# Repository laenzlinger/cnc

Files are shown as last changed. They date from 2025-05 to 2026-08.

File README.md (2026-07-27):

# SRCNC

This repository contains the code for my SRCNC project.
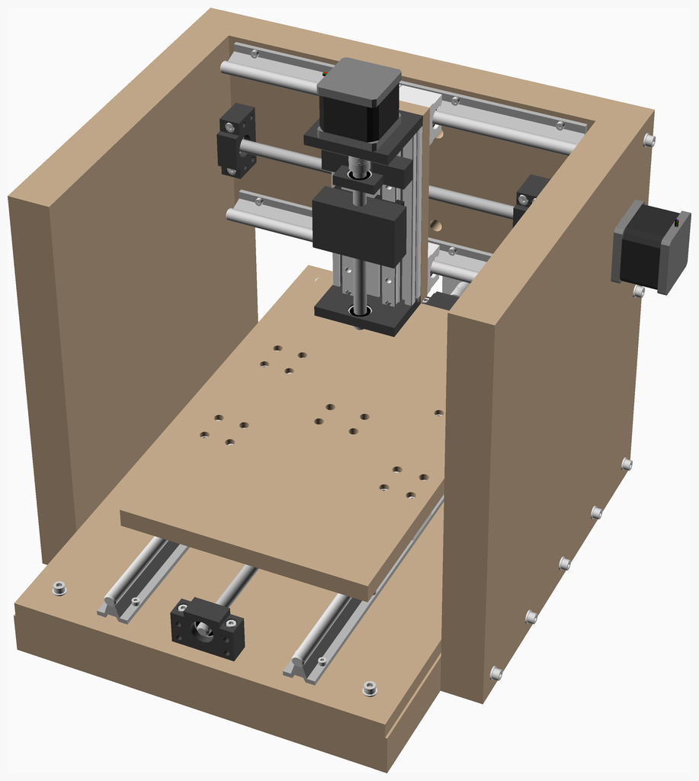
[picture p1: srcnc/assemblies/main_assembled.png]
Main Assembly


It contains configurations for my machine and several parts that I have designed for my CNC machine.

## Assembly

See [instructions](srcnc/readme.md)

## BOM

The below table just lists the main components. For a complete BOM see the assembly instructions above.

| Amount | Description | Source |
|--:|:---|:---|
|  2 | SBR12UU, rail 550mm | [AliExpress](https://www.aliexpress.com/item/1005008976304126.html) |
|  2 | SBR12UU, rail 350mm | [AliExpress](https://www.aliexpress.com/item/1005008976304126.html) |
|  1 | SFU1204 Set, 550mm | [AliExpress](https://www.aliexpress.com/item/1005004058956836.html) |
|  1 | SFU1204 Set, 350mm | [AliExpress](https://www.aliexpress.com/item/1005004058956836.html) |
|  1 | Openbuilds Nema 23 Stepper Motor Mount | [AliExpress](https://www.aliexpress.com/item/1005008656695586.html) |
|  3 | Nema 23 Stepper Motor | [AliExpress](https://www.aliexpress.com/item/1005006435245504.html) |
|  5 | CR10 Endstop | [AliExpress](https://www.aliexpress.com/item/1005001599112235.html) |
| 16 | M6 Threaded insert nut | [AliExpress](https://www.aliexpress.com/item/1005008275463912.html) |
|  1 | Openbuilds Router Spindle Mount 65mm | [AliExpress](https://www.aliexpress.com/item/1005007218914903.html) |
|  1 | Double Square Linear Guide Sliding Table 100mm | [AliExpress](https://www.aliexpress.com/item/1005005320373835.html) |

## Electronics

Built following [PrintNC electronics guidelines](https://wiki.printnc.info/en/electronics) for future migration to a PrintNC build.

| Amount | Description | Source |
|--:|:---|:---|
|  1 | MKS DLC32 MAX V1.1 (ESP32-S3) | [AliExpress](https://www.aliexpress.com/item/1005005320373835.html) |
|  3 | DM542T Stepper Driver | |
|  1 | HLTNC 3D Touch Probe | |
|  1 | Auto-zero Z Touch Plate | |

Spindle: Manual router (no VFD)

Firmware: [FluidNC v4.0.3](https://github.com/bdring/FluidNC)

See [wiring documentation](fluidnc/SRcnc-dlc32max/README.md)

## Libs

<https://github.com/nophead/NopSCADlib>

## Repository Structure

```
cnc/
  fluidnc/          — FluidNC firmware configs (MKS DLC32 MAX, TinyBee)
  grblhal/          — grblHAL configs (Flexi-HAL, future)
  ugs/              — Universal G-code Sender config and macros
  probe/            — Automated probe setup script (center finding, angle, Z)
  srcnc/            — Machine design (OpenSCAD + NopSCADlib)
    surfacing/      — Wasteboard surfacing G-code
  tools/            — FreeCAD tool library (bits + libraries)
  parts/
    BOSL2/          — OpenSCAD library (git submodule)
    calibrate/      — Calibration square
    coffee-time/    — First test job
    dc-plate/       — Electronics panel
    end-stop/       — End-stop mount
    fixture-plate/  — MDF fixture plate for Hammond 1590DD top panel milling
    flexi-hal/      — FlexiHAL mounting parts
```

## Workflow

See [SENDERS.md](SENDERS.md) for the complete operating workflow including
probe setup, macros, and the top panel milling procedure.

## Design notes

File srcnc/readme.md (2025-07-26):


# Srcnc
Small rigid CNC.

Main Assembly

<span></span>

---
## Table of Contents
1. [Parts list](#Parts_list)
1. [Zaxis Assembly](#zaxis_assembly)
1. [Xaxis Assembly](#xaxis_assembly)
1. [Yaxis Assembly](#yaxis_assembly)
1. [Frame Assembly](#Frame_assembly)
1. [Main Assembly](#main_assembly)

<span></span>
[Top](#TOP)

---

## Parts list
| <span style="writing-mode: vertical-rl; text-orientation: mixed;">Zaxis</span> | <span style="writing-mode: vertical-rl; text-orientation: mixed;">Xaxis</span> | <span style="writing-mode: vertical-rl; text-orientation: mixed;">Yaxis</span> | <span style="writing-mode: vertical-rl; text-orientation: mixed;">Frame</span> | <span style="writing-mode: vertical-rl; text-orientation: mixed;">Main</span> | <span style="writing-mode: vertical-rl; text-orientation: mixed;">TOTALS</span> |  |
|---:|---:|---:|---:|---:|---:|:---|
|  |  |  |  |  | | **Vitamins** |
| &nbsp;&nbsp;.&nbsp; | &nbsp;&nbsp;1&nbsp; | &nbsp;&nbsp;1&nbsp; | &nbsp;&nbsp;.&nbsp; | &nbsp;&nbsp;.&nbsp; |  &nbsp;&nbsp;2&nbsp; | &nbsp;&nbsp; BF10 floating ball screw support |
| &nbsp;&nbsp;.&nbsp; | &nbsp;&nbsp;1&nbsp; | &nbsp;&nbsp;1&nbsp; | &nbsp;&nbsp;.&nbsp; | &nbsp;&nbsp;.&nbsp; |  &nbsp;&nbsp;2&nbsp; | &nbsp;&nbsp; BK10 fixed ball screw support |
| &nbsp;&nbsp;.&nbsp; | &nbsp;&nbsp;1&nbsp; | &nbsp;&nbsp;.&nbsp; | &nbsp;&nbsp;.&nbsp; | &nbsp;&nbsp;.&nbsp; |  &nbsp;&nbsp;1&nbsp; | &nbsp;&nbsp; Chipboard 360mm x 200mm x 40mm |
| &nbsp;&nbsp;.&nbsp; | &nbsp;&nbsp;.&nbsp; | &nbsp;&nbsp;.&nbsp; | &nbsp;&nbsp;1&nbsp; | &nbsp;&nbsp;.&nbsp; |  &nbsp;&nbsp;1&nbsp; | &nbsp;&nbsp; Chipboard 360mm x 580mm x 40mm |
| &nbsp;&nbsp;.&nbsp; | &nbsp;&nbsp;.&nbsp; | &nbsp;&nbsp;.&nbsp; | &nbsp;&nbsp;2&nbsp; | &nbsp;&nbsp;.&nbsp; |  &nbsp;&nbsp;2&nbsp; | &nbsp;&nbsp; Chipboard 400mm x 360mm x 40mm |
| &nbsp;&nbsp;.&nbsp; | &nbsp;&nbsp;1&nbsp; | &nbsp;&nbsp;.&nbsp; | &nbsp;&nbsp;.&nbsp; | &nbsp;&nbsp;.&nbsp; |  &nbsp;&nbsp;1&nbsp; | &nbsp;&nbsp; Leadscrew 12 x 350mm, 4mm lead, 1 starts |
| &nbsp;&nbsp;.&nbsp; | &nbsp;&nbsp;.&nbsp; | &nbsp;&nbsp;1&nbsp; | &nbsp;&nbsp;.&nbsp; | &nbsp;&nbsp;.&nbsp; |  &nbsp;&nbsp;1&nbsp; | &nbsp;&nbsp; Leadscrew 12 x 550mm, 4mm lead, 1 starts |
| &nbsp;&nbsp;.&nbsp; | &nbsp;&nbsp;1&nbsp; | &nbsp;&nbsp;1&nbsp; | &nbsp;&nbsp;.&nbsp; | &nbsp;&nbsp;.&nbsp; |  &nbsp;&nbsp;2&nbsp; | &nbsp;&nbsp; Leadscrew Nut Housing |
| &nbsp;&nbsp;.&nbsp; | &nbsp;&nbsp;1&nbsp; | &nbsp;&nbsp;1&nbsp; | &nbsp;&nbsp;.&nbsp; | &nbsp;&nbsp;.&nbsp; |  &nbsp;&nbsp;2&nbsp; | &nbsp;&nbsp; Leadscrew Nut for SFU1204 |
| &nbsp;&nbsp;.&nbsp; | &nbsp;&nbsp;16&nbsp; | &nbsp;&nbsp;24&nbsp; | &nbsp;&nbsp;.&nbsp; | &nbsp;&nbsp;.&nbsp; |  &nbsp;&nbsp;40&nbsp; | &nbsp;&nbsp; Nut M4 x 3.2mm  |
| &nbsp;&nbsp;.&nbsp; | &nbsp;&nbsp;6&nbsp; | &nbsp;&nbsp;6&nbsp; | &nbsp;&nbsp;.&nbsp; | &nbsp;&nbsp;.&nbsp; |  &nbsp;&nbsp;12&nbsp; | &nbsp;&nbsp; Nut M5 x 4mm  |
| &nbsp;&nbsp;.&nbsp; | &nbsp;&nbsp;2&nbsp; | &nbsp;&nbsp;.&nbsp; | &nbsp;&nbsp;.&nbsp; | &nbsp;&nbsp;.&nbsp; |  &nbsp;&nbsp;2&nbsp; | &nbsp;&nbsp; SBR12 rail, length 350mm |
| &nbsp;&nbsp;.&nbsp; | &nbsp;&nbsp;.&nbsp; | &nbsp;&nbsp;2&nbsp; | &nbsp;&nbsp;.&nbsp; | &nbsp;&nbsp;.&nbsp; |  &nbsp;&nbsp;2&nbsp; | &nbsp;&nbsp; SBR12 rail, length 550mm |
| &nbsp;&nbsp;.&nbsp; | &nbsp;&nbsp;4&nbsp; | &nbsp;&nbsp;4&nbsp; | &nbsp;&nbsp;.&nbsp; | &nbsp;&nbsp;.&nbsp; |  &nbsp;&nbsp;8&nbsp; | &nbsp;&nbsp; SBR12UU bearing block |
| &nbsp;&nbsp;1&nbsp; | &nbsp;&nbsp;.&nbsp; | &nbsp;&nbsp;.&nbsp; | &nbsp;&nbsp;.&nbsp; | &nbsp;&nbsp;.&nbsp; |  &nbsp;&nbsp;1&nbsp; | &nbsp;&nbsp; SGX_5080 linear guide table |
| &nbsp;&nbsp;.&nbsp; | &nbsp;&nbsp;6&nbsp; | &nbsp;&nbsp;6&nbsp; | &nbsp;&nbsp;.&nbsp; | &nbsp;&nbsp;.&nbsp; |  &nbsp;&nbsp;12&nbsp; | &nbsp;&nbsp; Screw M4 cap x 15mm |
| &nbsp;&nbsp;.&nbsp; | &nbsp;&nbsp;.&nbsp; | &nbsp;&nbsp;24&nbsp; | &nbsp;&nbsp;.&nbsp; | &nbsp;&nbsp;.&nbsp; |  &nbsp;&nbsp;24&nbsp; | &nbsp;&nbsp; Screw M4 cap x 25mm |
| &nbsp;&nbsp;.&nbsp; | &nbsp;&nbsp;16&nbsp; | &nbsp;&nbsp;.&nbsp; | &nbsp;&nbsp;.&nbsp; | &nbsp;&nbsp;.&nbsp; |  &nbsp;&nbsp;16&nbsp; | &nbsp;&nbsp; Screw M4 cap x 50mm |
| &nbsp;&nbsp;.&nbsp; | &nbsp;&nbsp;16&nbsp; | &nbsp;&nbsp;16&nbsp; | &nbsp;&nbsp;.&nbsp; | &nbsp;&nbsp;.&nbsp; |  &nbsp;&nbsp;32&nbsp; | &nbsp;&nbsp; Screw M5 cap x 16mm |
| &nbsp;&nbsp;.&nbsp; | &nbsp;&nbsp;.&nbsp; | &nbsp;&nbsp;6&nbsp; | &nbsp;&nbsp;.&nbsp; | &nbsp;&nbsp;.&nbsp; |  &nbsp;&nbsp;6&nbsp; | &nbsp;&nbsp; Screw M5 cap x 47.5mm |
| &nbsp;&nbsp;.&nbsp; | &nbsp;&nbsp;6&nbsp; | &nbsp;&nbsp;.&nbsp; | &nbsp;&nbsp;.&nbsp; | &nbsp;&nbsp;.&nbsp; |  &nbsp;&nbsp;6&nbsp; | &nbsp;&nbsp; Screw M5 cap x 72.5mm |
| &nbsp;&nbsp;.&nbsp; | &nbsp;&nbsp;.&nbsp; | &nbsp;&nbsp;.&nbsp; | &nbsp;&nbsp;.&nbsp; | &nbsp;&nbsp;4&nbsp; |  &nbsp;&nbsp;4&nbsp; | &nbsp;&nbsp; Screw M6 cap x 20mm |
| &nbsp;&nbsp;.&nbsp; | &nbsp;&nbsp;.&nbsp; | &nbsp;&nbsp;.&nbsp; | &nbsp;&nbsp;16&nbsp; | &nbsp;&nbsp;.&nbsp; |  &nbsp;&nbsp;16&nbsp; | &nbsp;&nbsp; Screw M6 cap x 55mm |
| &nbsp;&nbsp;1&nbsp; | &nbsp;&nbsp;1&nbsp; | &nbsp;&nbsp;1&nbsp; | &nbsp;&nbsp;.&nbsp; | &nbsp;&nbsp;.&nbsp; |  &nbsp;&nbsp;3&nbsp; | &nbsp;&nbsp; Shaft coupling SC_8x8_flex |
| &nbsp;&nbsp;.&nbsp; | &nbsp;&nbsp;.&nbsp; | &nbsp;&nbsp;1&nbsp; | &nbsp;&nbsp;.&nbsp; | &nbsp;&nbsp;.&nbsp; |  &nbsp;&nbsp;1&nbsp; | &nbsp;&nbsp; Sheet MDF 356mm x 580mm x 15mm |
| &nbsp;&nbsp;.&nbsp; | &nbsp;&nbsp;.&nbsp; | &nbsp;&nbsp;1&nbsp; | &nbsp;&nbsp;.&nbsp; | &nbsp;&nbsp;.&nbsp; |  &nbsp;&nbsp;1&nbsp; | &nbsp;&nbsp; Sheet MDF 400mm x 240mm x 18mm |
| &nbsp;&nbsp;.&nbsp; | &nbsp;&nbsp;1&nbsp; | &nbsp;&nbsp;.&nbsp; | &nbsp;&nbsp;.&nbsp; | &nbsp;&nbsp;.&nbsp; |  &nbsp;&nbsp;1&nbsp; | &nbsp;&nbsp; Sheet MDF 80mm x 200mm x 15mm |
| &nbsp;&nbsp;1&nbsp; | &nbsp;&nbsp;1&nbsp; | &nbsp;&nbsp;1&nbsp; | &nbsp;&nbsp;.&nbsp; | &nbsp;&nbsp;.&nbsp; |  &nbsp;&nbsp;3&nbsp; | &nbsp;&nbsp; Stepper motor NEMA22 x 51.2mm (6.35x24 shaft) |
| &nbsp;&nbsp;.&nbsp; | &nbsp;&nbsp;.&nbsp; | &nbsp;&nbsp;.&nbsp; | &nbsp;&nbsp;16&nbsp; | &nbsp;&nbsp;4&nbsp; |  &nbsp;&nbsp;20&nbsp; | &nbsp;&nbsp; Threaded insert M6 x 15mm |
| &nbsp;&nbsp;.&nbsp; | &nbsp;&nbsp;16&nbsp; | &nbsp;&nbsp;24&nbsp; | &nbsp;&nbsp;.&nbsp; | &nbsp;&nbsp;.&nbsp; |  &nbsp;&nbsp;40&nbsp; | &nbsp;&nbsp; Washer  M4 x 9mm x 0.8mm |
| &nbsp;&nbsp;.&nbsp; | &nbsp;&nbsp;6&nbsp; | &nbsp;&nbsp;6&nbsp; | &nbsp;&nbsp;.&nbsp; | &nbsp;&nbsp;.&nbsp; |  &nbsp;&nbsp;12&nbsp; | &nbsp;&nbsp; Washer  M5 x 10mm x 1mm |
| &nbsp;&nbsp;.&nbsp; | &nbsp;&nbsp;.&nbsp; | &nbsp;&nbsp;.&nbsp; | &nbsp;&nbsp;16&nbsp; | &nbsp;&nbsp;4&nbsp; |  &nbsp;&nbsp;20&nbsp; | &nbsp;&nbsp; Washer  M6 x 12.5mm x 1.5mm |
| &nbsp;&nbsp;3&nbsp; | &nbsp;&nbsp;103&nbsp; | &nbsp;&nbsp;127&nbsp; | &nbsp;&nbsp;51&nbsp; | &nbsp;&nbsp;12&nbsp; | &nbsp;&nbsp;296&nbsp; | &nbsp;&nbsp;Total vitamins count |
|  |  |  |  |  | | **3D printed parts** |
| &nbsp;&nbsp;.&nbsp; | &nbsp;&nbsp;1&nbsp; | &nbsp;&nbsp;1&nbsp; | &nbsp;&nbsp;.&nbsp; | &nbsp;&nbsp;.&nbsp; |  &nbsp;&nbsp;2&nbsp; | &nbsp;&nbsp;nut_housing_adapter.stl |
| &nbsp;&nbsp;.&nbsp; | &nbsp;&nbsp;.&nbsp; | &nbsp;&nbsp;1&nbsp; | &nbsp;&nbsp;.&nbsp; | &nbsp;&nbsp;.&nbsp; |  &nbsp;&nbsp;1&nbsp; | &nbsp;&nbsp;waste_board.stl |
| &nbsp;&nbsp;.&nbsp; | &nbsp;&nbsp;1&nbsp; | &nbsp;&nbsp;.&nbsp; | &nbsp;&nbsp;.&nbsp; | &nbsp;&nbsp;.&nbsp; |  &nbsp;&nbsp;1&nbsp; | &nbsp;&nbsp;zplate.stl |
| &nbsp;&nbsp;.&nbsp; | &nbsp;&nbsp;2&nbsp; | &nbsp;&nbsp;2&nbsp; | &nbsp;&nbsp;.&nbsp; | &nbsp;&nbsp;.&nbsp; | &nbsp;&nbsp;4&nbsp; | &nbsp;&nbsp;Total 3D printed parts count |
|  |  |  |  |  | | **CNC routed parts** |
| &nbsp;&nbsp;.&nbsp; | &nbsp;&nbsp;.&nbsp; | &nbsp;&nbsp;.&nbsp; | &nbsp;&nbsp;1&nbsp; | &nbsp;&nbsp;.&nbsp; |  &nbsp;&nbsp;1&nbsp; | &nbsp;&nbsp;frame_bottom_side.dxf |
| &nbsp;&nbsp;.&nbsp; | &nbsp;&nbsp;.&nbsp; | &nbsp;&nbsp;.&nbsp; | &nbsp;&nbsp;1&nbsp; | &nbsp;&nbsp;.&nbsp; |  &nbsp;&nbsp;1&nbsp; | &nbsp;&nbsp;frame_left_side.dxf |
| &nbsp;&nbsp;.&nbsp; | &nbsp;&nbsp;.&nbsp; | &nbsp;&nbsp;.&nbsp; | &nbsp;&nbsp;1&nbsp; | &nbsp;&nbsp;.&nbsp; |  &nbsp;&nbsp;1&nbsp; | &nbsp;&nbsp;frame_right_side.dxf |
| &nbsp;&nbsp;.&nbsp; | &nbsp;&nbsp;1&nbsp; | &nbsp;&nbsp;.&nbsp; | &nbsp;&nbsp;.&nbsp; | &nbsp;&nbsp;.&nbsp; |  &nbsp;&nbsp;1&nbsp; | &nbsp;&nbsp;xplate.dxf |
| &nbsp;&nbsp;.&nbsp; | &nbsp;&nbsp;.&nbsp; | &nbsp;&nbsp;1&nbsp; | &nbsp;&nbsp;.&nbsp; | &nbsp;&nbsp;.&nbsp; |  &nbsp;&nbsp;1&nbsp; | &nbsp;&nbsp;yplate.dxf |
| &nbsp;&nbsp;.&nbsp; | &nbsp;&nbsp;1&nbsp; | &nbsp;&nbsp;1&nbsp; | &nbsp;&nbsp;3&nbsp; | &nbsp;&nbsp;.&nbsp; | &nbsp;&nbsp;5&nbsp; | &nbsp;&nbsp;Total CNC routed parts count |

<span></span>
[Top](#TOP)

---

## Zaxis Assembly
### Vitamins
|Qty|Description|
|---:|:---|
|1| SGX_5080 linear guide table|
|1| Shaft coupling SC_8x8_flex|
|1| Stepper motor NEMA22 x 51.2mm (6.35x24 shaft)|

### Assembly instructions
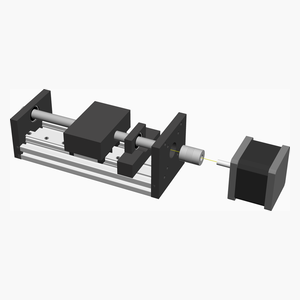
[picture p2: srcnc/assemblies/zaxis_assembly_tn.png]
zaxis_assembly


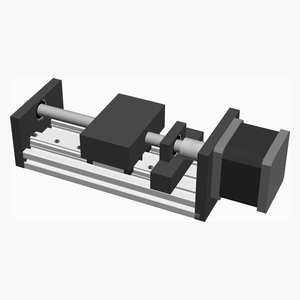
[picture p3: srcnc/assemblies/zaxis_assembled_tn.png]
zaxis_assembled


<span></span>
[Top](#TOP)

---

## Xaxis Assembly
### Vitamins
|Qty|Description|
|---:|:---|
|1| BF10 floating ball screw support|
|1| BK10 fixed ball screw support|
|1| Chipboard 360mm x 200mm x 40mm|
|1| Leadscrew 12 x 350mm, 4mm lead, 1 starts|
|1| Leadscrew Nut Housing|
|1| Leadscrew Nut for SFU1204|
|16| Nut M4 x 3.2mm |
|6| Nut M5 x 4mm |
|2| SBR12 rail, length 350mm|
|4| SBR12UU bearing block|
|6| Screw M4 cap x 15mm|
|16| Screw M4 cap x 50mm|
|16| Screw M5 cap x 16mm|
|6| Screw M5 cap x 72.5mm|
|1| Shaft coupling SC_8x8_flex|
|1| Sheet MDF 80mm x 200mm x 15mm|
|1| Stepper motor NEMA22 x 51.2mm (6.35x24 shaft)|
|16| Washer  M4 x 9mm x 0.8mm|
|6| Washer  M5 x 10mm x 1mm|

### 3D Printed parts

| 1 x [nut_housing_adapter.stl](stls/nut_housing_adapter.stl) | 1 x [zplate.stl](stls/zplate.stl) |
|---|---|
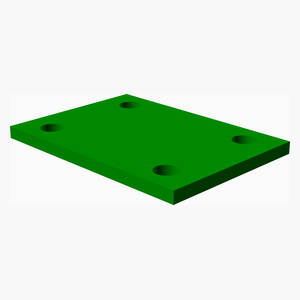
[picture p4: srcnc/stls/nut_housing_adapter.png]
nut_housing_adapter.stl
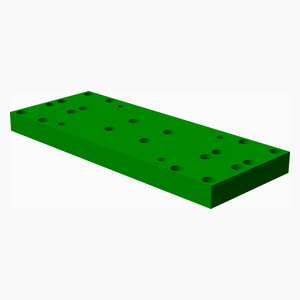
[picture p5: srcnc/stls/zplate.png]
zplate.stl
|  |  

### CNC Routed parts

| 1 x [xplate.dxf](dxfs/xplate.dxf) |
|---|
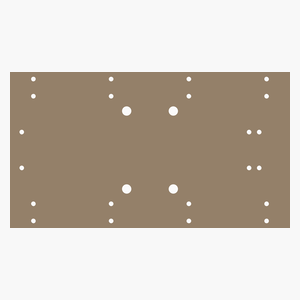
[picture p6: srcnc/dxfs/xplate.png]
xplate.dxf
|  

### Sub-assemblies

| 1 x zaxis_assembly |
|---|
| zaxis_assembled 

### Assembly instructions
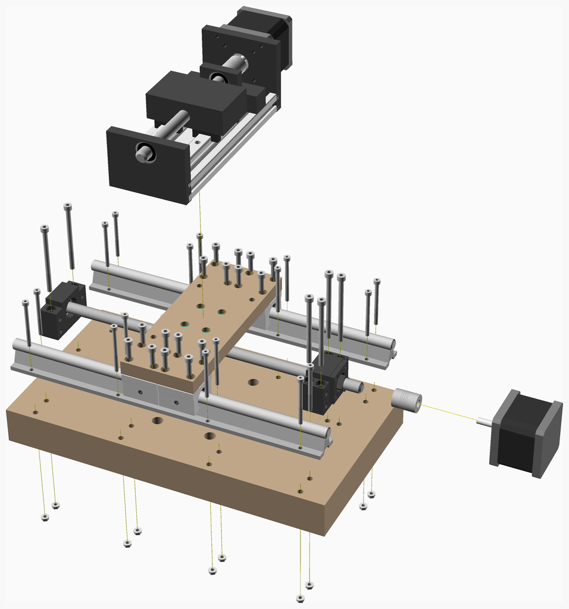
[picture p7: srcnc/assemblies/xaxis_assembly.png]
xaxis_assembly


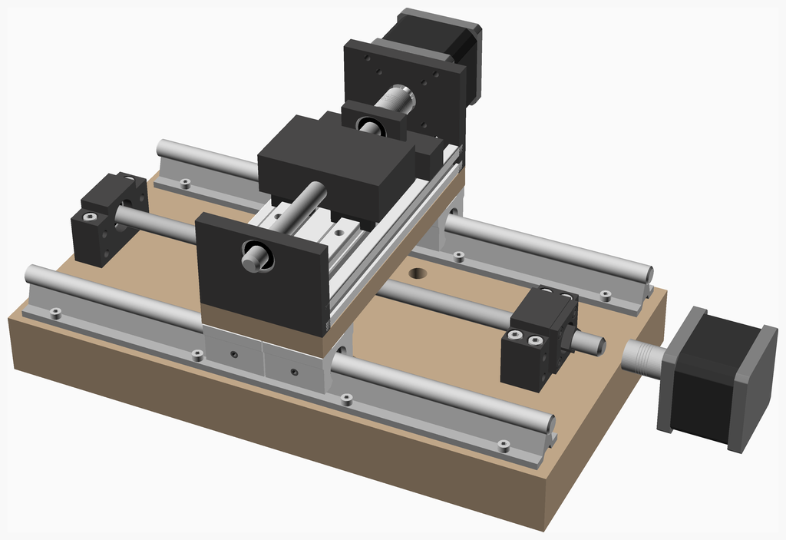
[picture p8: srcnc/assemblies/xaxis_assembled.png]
xaxis_assembled


<span></span>
[Top](#TOP)

---

## Yaxis Assembly
### Vitamins
|Qty|Description|
|---:|:---|
|1| BF10 floating ball screw support|
|1| BK10 fixed ball screw support|
|1| Leadscrew 12 x 550mm, 4mm lead, 1 starts|
|1| Leadscrew Nut Housing|
|1| Leadscrew Nut for SFU1204|
|24| Nut M4 x 3.2mm |
|6| Nut M5 x 4mm |
|2| SBR12 rail, length 550mm|
|4| SBR12UU bearing block|
|6| Screw M4 cap x 15mm|
|24| Screw M4 cap x 25mm|
|16| Screw M5 cap x 16mm|
|6| Screw M5 cap x 47.5mm|
|1| Shaft coupling SC_8x8_flex|
|1| Sheet MDF 356mm x 580mm x 15mm|
|1| Sheet MDF 400mm x 240mm x 18mm|
|1| Stepper motor NEMA22 x 51.2mm (6.35x24 shaft)|
|24| Washer  M4 x 9mm x 0.8mm|
|6| Washer  M5 x 10mm x 1mm|

### 3D Printed parts

| 1 x [nut_housing_adapter.stl](stls/nut_housing_adapter.stl) | 1 x [waste_board.stl](stls/waste_board.stl) |
|---|---|
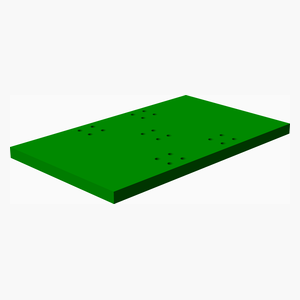
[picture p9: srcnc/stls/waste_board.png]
waste_board.stl
| nut_housing_adapter.stl |  

### CNC Routed parts

| 1 x [yplate.dxf](dxfs/yplate.dxf) |
|---|
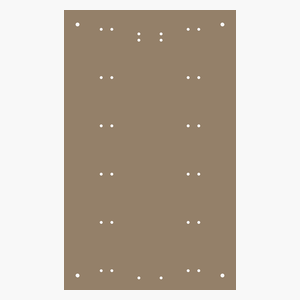
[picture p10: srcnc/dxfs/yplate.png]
yplate.dxf
|  

### Assembly instructions
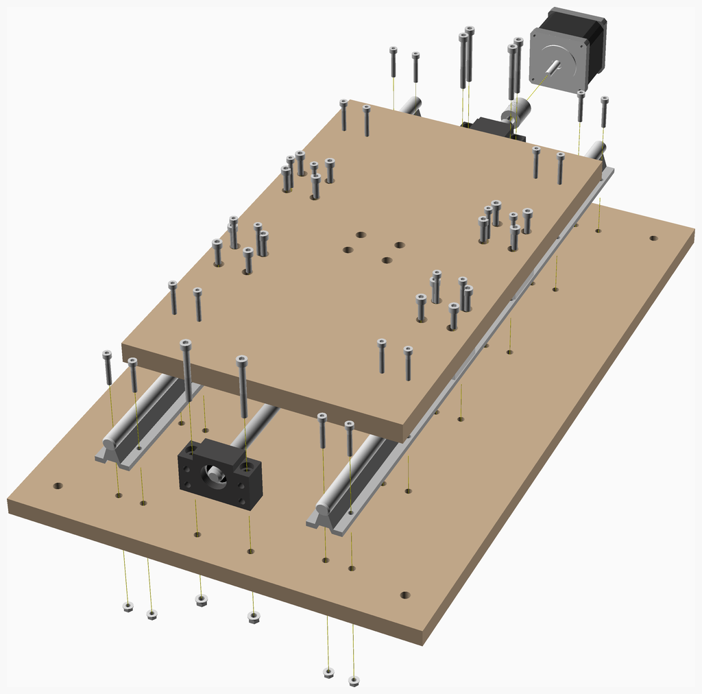
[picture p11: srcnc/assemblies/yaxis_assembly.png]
yaxis_assembly


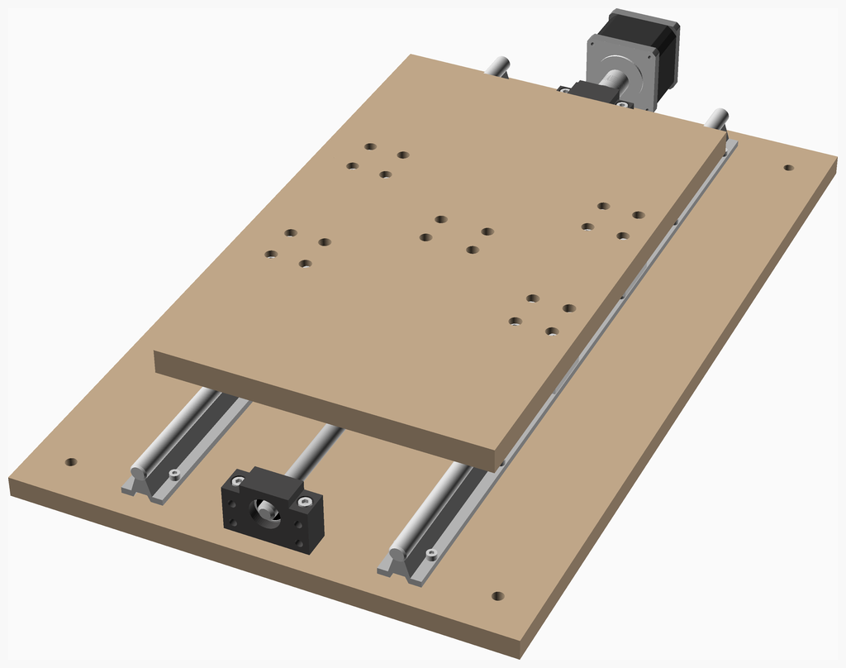
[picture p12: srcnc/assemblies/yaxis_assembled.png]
yaxis_assembled


<span></span>
[Top](#TOP)

---

## Frame Assembly
### Vitamins
|Qty|Description|
|---:|:---|
|1| Chipboard 360mm x 580mm x 40mm|
|2| Chipboard 400mm x 360mm x 40mm|
|16| Screw M6 cap x 55mm|
|16| Threaded insert M6 x 15mm|
|16| Washer  M6 x 12.5mm x 1.5mm|

### CNC Routed parts

| 1 x [frame_bottom_side.dxf](dxfs/frame_bottom_side.dxf) | 1 x [frame_left_side.dxf](dxfs/frame_left_side.dxf) | 1 x [frame_right_side.dxf](dxfs/frame_right_side.dxf) |
|---|---|---|
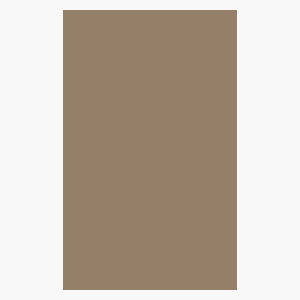
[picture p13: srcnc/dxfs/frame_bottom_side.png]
frame_bottom_side.dxf
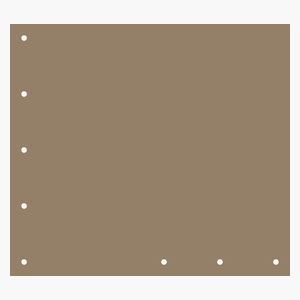
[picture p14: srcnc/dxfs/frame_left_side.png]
frame_left_side.dxf
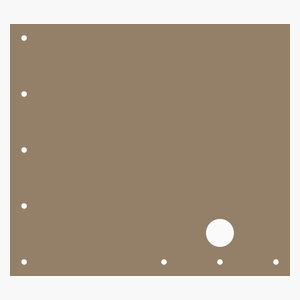
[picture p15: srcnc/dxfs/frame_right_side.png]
frame_right_side.dxf
|  |  |  

### Assembly instructions
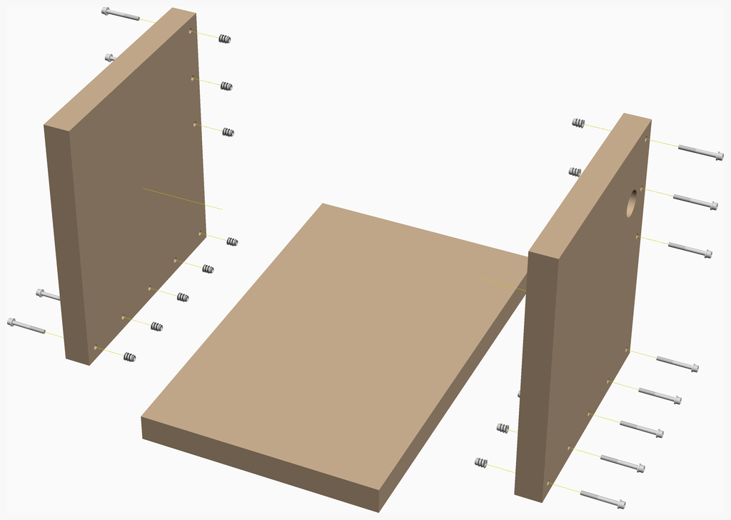
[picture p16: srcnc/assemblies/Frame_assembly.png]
Frame_assembly


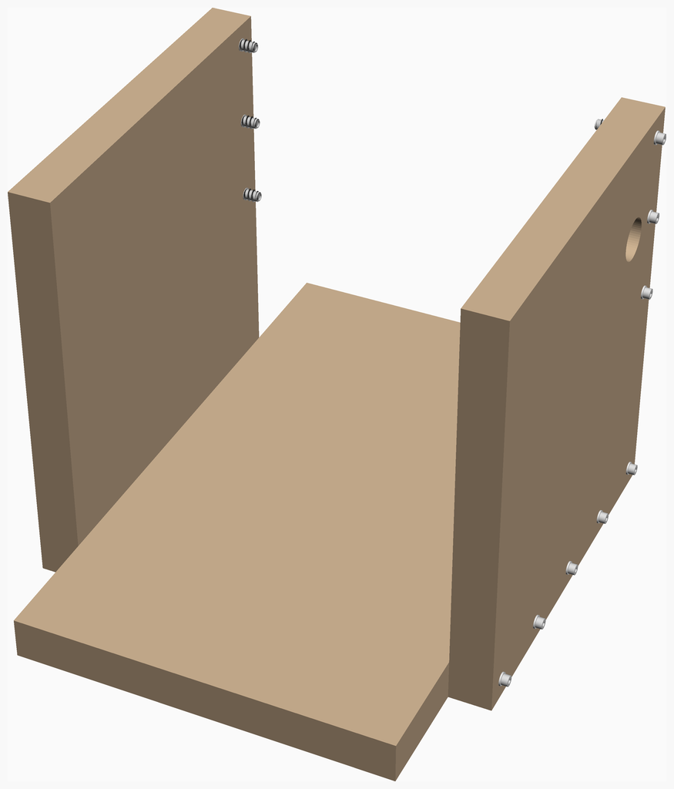
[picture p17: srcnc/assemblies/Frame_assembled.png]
Frame_assembled


<span></span>
[Top](#TOP)

---

## Main Assembly
### Vitamins
|Qty|Description|
|---:|:---|
|4| Screw M6 cap x 20mm|
|4| Threaded insert M6 x 15mm|
|4| Washer  M6 x 12.5mm x 1.5mm|

### Sub-assemblies

| 1 x Frame_assembly | 1 x xaxis_assembly | 1 x yaxis_assembly |
|---|---|---|
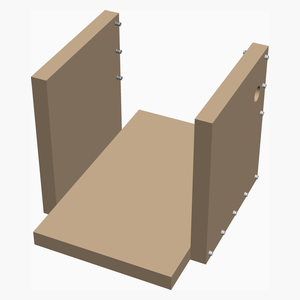
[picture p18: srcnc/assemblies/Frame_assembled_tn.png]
Frame_assembled
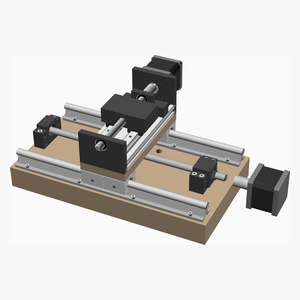
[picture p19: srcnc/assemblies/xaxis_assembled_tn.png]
xaxis_assembled
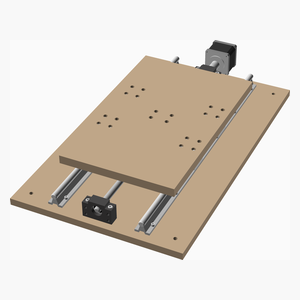
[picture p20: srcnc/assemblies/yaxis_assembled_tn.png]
yaxis_assembled
|  |  |  

### Assembly instructions
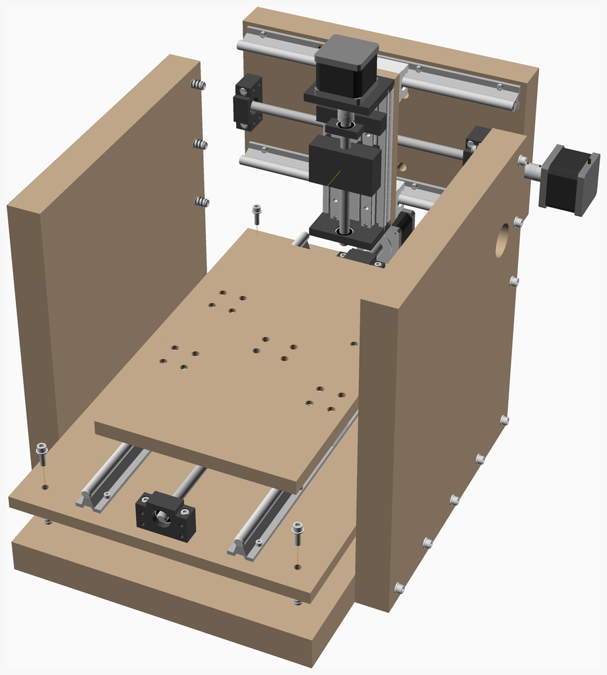
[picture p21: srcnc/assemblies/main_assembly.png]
main_assembly


Assembly instructions in Markdown format in front of each module that makes an assembly.

main_assembled

<span></span>
[Top](#TOP)

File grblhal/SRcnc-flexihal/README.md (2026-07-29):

# SRcnc — Flexi-HAL Wiring

## Board

Flexi-HAL CNC Controller (Expatria Technologies, STM32F446)

Firmware: grblHAL

### Firmware Build

- File: `FLEXI_HAL_3AXIS_PRB_20250311_120325.uf2`
- Source: https://github.com/Expatria-Technologies/STM32F4xx/releases
- Release: Stable 1.0.1.6
- Config: 3 axis, probe support, no Ethernet/SD
- Driver: STM32F446, version 250311
- Board ID: FlexiHAL_20250311_120325

To upgrade: double-tap RST, copy new .uf2 to FLEXI446 drive, re-apply settings.txt

## Stepper Drivers

3x DM542T (external step/dir drivers)

Supply: 45V DC

### DM542T DIP Switch Settings

Motor: NEMA 23, 57x56mm, 3A, 1.8°, 1.2 N.m

| SW  | Position | Function |
|-----|---|---|
| SW1 | OFF | Peak current 3.0A |
| SW2 | OFF | |
| SW3 | ON | |
| SW4 | OFF | Microstep: 8 (1600 pulses/rev) |
| SW5 | ON | |
| SW6 | OFF | |
| SW7 | OFF | Self-test OFF |
| SW8 | OFF | No half-current at idle |

Result: 8 microsteps → 1600 pulses/rev → 400 steps/mm (with SFU1204, 4mm pitch)

### Flexi-HAL to DM542T Connection

8-pin IDC ribbon cable from Flexi-HAL stepper port to DM542T screw terminals.

Flexi-HAL stepper port pinout (from documentation):

| IDC Pin | Signal | DM542T Terminal |
|---|---|---|
| 1 | S+ | PUL+ |
| 2 | S- | PUL- |
| 3 | D+ | DIR+ |
| 4 | D- | DIR- |
| 5 | 5V | ENA+ |
| 6 | E- | ENA- |
| 7 | G | GND |
| 8 | AL- | ALM+ |

Note: Verify exact pinout against Flexi-HAL documentation when board arrives.
The differential signals provide full 5V swing with proper isolation.

### Motor Aviation Connector (GX16-5)

5-pin aviation connector between DM542T and NEMA 23 motor:

| Pin | Signal | Connector Wire | Motor Wire (57BYG250B-8) |
|-----|---|---|---|
| 1 | A+ | Red | Black |
| 2 | A- | Yellow | Green |
| 3 | GND | Black | (shield) |
| 4 | B+ | Blue | Red |
| 5 | B- | Green | Blue |

Same pinout and color coding for all 3 axes.

## Limit Switches

CR10 endstop switches (NO). Future upgrade: NPN NC inductive proximity sensors.

Connected to Flexi-HAL limit inputs (RJ45 breakout or direct PCB terminals).

Configure as NO in GRBLHAL: `$5=0`

### Endstop Aviation Connector (GX12-4)

| Pin | Signal | Current (CR10) | Future (inductive) |
|-----|---|---|---|
| 1 | GND | GND | GND |
| 2 | 5V | LED power | (unused) |
| 3 | Signal | Switch NO | Signal NPN NC |
| 4 | spare  | (unused) | 12V sensor power  |

Per-axis cable colors:

| Pin | Signal | X Color | Y Color | Z Color |
|-----|---|---|---|---|
| 1 | GND | Blue | Black | White |
| 2 | 5V | Red | Yellow  | Brown |
| 3 | Signal | Gray | Green | Green |
| 4 | spare  | — | — | — |

## Probes

| Probe | Connection |
|---|---|
| HLTNC 3D Touch | Probe input (NPN-NO, 5V powered) |
| Z Tool Setter | Toolsetter input (NC) |
| Z Tool Setter Overtravel | Alarm/E-stop input (NC) |

### HLTNC 3D Touch Probe (NPN-NO, USB-C, 5V)

Same as DLC32 MAX setup. See main wiring docs.

### Z Tool Setter (AllyCircle, NC switch, spring-loaded)

| Wire | Signal | Flexi-HAL Connection |
|---|---|---|
| Red | Probe (NC) | Toolsetter input |
| Black  | Probe GND | GND |
| Yellow | Overtravel (NC) | Alarm/E-stop input |
| Green  | Overtravel GND  | GND |

Configure as NC (normally closed) in grblHAL: `$6=1` (invert probe pin)
Overtravel connects to alarm input for crash protection.

## USB Connection

Laptop → USB-C to USB-A cable → USB-A panel mount (enclosure) → USB-A to USB-C cable → Flexi-HAL

## Power

| Device | Voltage | Source |
|---|---|---|
| Flexi-HAL | 12-24V  | 24V PSU |
| DM542T (x3)  | 45V | 45V PSU |

## DIN Rail Layout

- Flexi-HAL (3D printed DIN mount from Expatria)
- 3x DM542T
- 24V PSU
- 45V PSU
- USB-A panel mount on enclosure wall

## GRBLHAL Settings

| Setting | Value | Description |
|---|---|---|
| $100 | 400 | X steps/mm  |
| $101 | 400 | Y steps/mm  |
| $102 | 400 | Z steps/mm  |
| $110 | 800 | X max rate mm/min |
| $111 | 800 | Y max rate mm/min |
| $112 | 400 | Z max rate mm/min |
| $120 | 20 | X acceleration mm/s² |
| $121 | 20 | Y acceleration mm/s² |
| $122 | 20 | Z acceleration mm/s² |
| $130 | 220 | X max travel mm |
| $131 | 380 | Y max travel mm |
| $132 | 95 | Z max travel mm |
| $5 | 7 | Limit pins invert (NO switches, bitmask X+Y+Z=7) |
| $20 | 1 | Soft limits enabled |
| $21 | 1 | Hard limits enabled |
| $22 | 1 | Homing enabled |

## Notes

- The Flexi-HAL uses isolated differential drivers for step/dir signals — no level shifter needed.
- Alarm feedback from DM542T is supported on pin 7/8 of the IDC connector (future wiring).
- The board communicates via USB-C serial to bCNC or UGS.
- FluidDial pendant is NOT compatible — use Jog2K or keyboard jogging via bCNC.

## Parts to Order

| Part | Quantity | Notes |
|---|---|---|
| 28AWG 8-conductor IDC flat ribbon cable | 1m | For Flexi-HAL to DM542T connections |
| USB-A to USB-C cable (~30cm) | 1x | Inside enclosure: panel mount to Flexi-HAL |

Note: IDC connectors and screw terminal plugs are included with the Flexi-HAL board.

## Parts to Print

| File | Material | Notes |
|---|---|---|
| `parts/flexi-hal/DIN_Clip.stl` | PETG | DIN rail clip |
| `parts/flexi-hal/Flexi-HAL_Mount_Plate.stl` | PETG | Board mounting plate |

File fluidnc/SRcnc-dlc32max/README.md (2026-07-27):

# SRcnc — MKS DLC32 MAX V1.1 Wiring

Pin assignments from MKS DLC32 MAX V1.0.002 pin diagram (KiCad, 2024-11-04).

## Board

MKS DLC32 MAX V1.1 (ESP32-S3)

## Board Connector Layout

```
                         TOP EDGE
 ┌─────────────────────────────────────────────────────────────────┐
 │  X-MOTOR  Y1-MOTOR  Y2-MOTOR  Z-MOTOR  A-MOTOR   AIR  BEEPER  │
 │  2B2A1B1A 2B2A1B1A  2B2A1B1A  2B2A1B1A 2B2A1B1A  IO1   IO42   │
 │                                                                  │
 ├────┐                                                      ┌─────┤
 │GND │                                                      │Z-LMT│
 │12- │                                                      │IO41 │
 │24V │                                                      │Y-LMT│
 │    │                                                      │IO40 │
 ├────┤             MKS DLC32 MAX V1.0                       │X-LMT│
 │Laser                                                      │IO39 │
 │IO2 │                                                      ├─────┤
 ├────┤                                                      │Door │
 │Laser                                                      │IO38 │
 │IO2 │                                                      │Flame│
 ├────┤                                                      │IO36 │
 │Spin│                                                      │Probe│
 │IO35│                                                      │IO37 │
 ├────┤                                                      │A-LMT│
 │SWIT│                                                      │IO48 │
 │CH  │                                                      ├─────┤
 ├────┘                                                      │ U1  │
 │  POWER        SD Card                                     │RJ11 │
 │  DC12V/24V    IO12,IO13,IO14,IO21                    GND RESET  │
 └─────────────────────────────────────────────────────────────────┘
                        BOTTOM EDGE
```

## Connector Pinout Table

### Top Edge — Motor Connectors

| Connector  | Function | Pins | Wire To |
|---|---|---|---|
| X-MOTOR | X stepper | Step: IO16, Dir: IO15 | DM542T #1 |
| Y1-MOTOR | Y stepper | Step: IO7, Dir: IO6 | DM542T #2 |
| Y2-MOTOR | Y2 stepper | (unused) | — |
| Z-MOTOR | Z stepper | Step: IO5, Dir: IO4 | DM542T #3 |
| A-MOTOR | A stepper | Step: IO20, Dir: IO19 | (spare) |
| AIR | Air assist | IO1 | (unused) |
| BEEPER | Buzzer | IO42 | (unused) |

All motors share enable on **IO8**.

### Right Edge — Limit Switches & Sensors

| Connector  | Pin | Signal | Wire To |
|---|---|---|---|
| Z- LMT | IO41 | Z limit | CR10 endstop (Z top) |
| Y- LMT | IO40 | Y limit | CR10 endstop (Y min) |
| X- LMT | IO39 | X limit | CR10 endstop (X home)  |
| Door | IO38 | Safety door | (unused) |
| Flame | IO36 | Flame sensor| Z Tool Setter (AllyCircle, NC) |
| Probe | IO37 | Probe input | HLTNC 3D Touch Probe or Z touch plate (swap as needed) |
| A- LMT | IO48 | A limit | (unused) |

Endstop wiring: connect "S" and "G" pins (Signal + GND). Board has internal pull-ups.

### Endstop Aviation Connector (GX12-4)

4-pin aviation connector between board and CR10 endstop:

Board endstop socket pin order: **5V, GND, IO** (Signal)

| Pin | Signal | Board Socket Pin | Wire Color |
|-----|---|---|---|
| 1 | GND | 2 (GND) | Brown |
| 2 | 5V | 1 (5V) | Black |
| 3 | Signal | 3 (IO) | Blue |
| 4 | spare  | — | (future 12V for inductive sensors) |

Same pinout and colors for all 3 axes.

Internal wiring colors (board to aviation connector, per axis):

| Pin | Signal | X Color | Y Color | Z Color |
|-----|---|---|---|---|
| 1 | GND | Blue | Black | White |
| 2 | 5V | Red | Yellow  | Brown |
| 3 | Signal | Gray | Green | Green |

### Left Edge — Power & Outputs

| Connector  | Pin | Function | Wire To |
|---|---|---|---|
| GND 12-24V | — | Motor power GND | DM542T GND (shared)  |
| Laser IO2  | IO2 | PWM output | (future: spindle PWM)|
| Laser IO2  | IO2 | PWM output (2nd)| Same signal, higher power connector |
| Spindle | IO35  | Spindle enable  | (future: spindle on/off) |
| SWITCH | — | External power switch | (optional) |

### Bottom Edge

| Connector  | Function | Wire To |
|---|---|---|
| POWER | DC 12-24V input | PSU |
| U1 (RJ11) | UART TX:IO17 RX:IO18 | FluidDial pendant |
| GND RESET  | Reset / E-stop | (optional) |

## Wiring Summary — What Gets Connected

| Device | Board Connector | Pin(s) |
|---|---|---|
| DM542T #1 (X) | X-MOTOR (EXT) | Step:IO16, Dir:IO15, En:IO8 |
| DM542T #2 (Y) | Y1-MOTOR (EXT)  | Step:IO7, Dir:IO6, En:IO8 |
| DM542T #3 (Z) | Z-MOTOR (EXT) | Step:IO5, Dir:IO4, En:IO8 |
| CR10 endstop X | X- LMT | IO39 |
| CR10 endstop Y | Y- LMT | IO40 |
| CR10 endstop Z | Z- LMT | IO41 |
| HLTNC 3D Touch Probe  | Probe | IO37 |
| Z Tool Setter (spring)| Flame | IO36 |
| Z Touch Plate | Probe | IO37 (swap with 3D probe as needed) |
| FluidDial pendant | U1 (RJ11) | TX:IO17, RX:IO18 |
| PSU 24V | POWER | DC 12-24V |
| DM542T power | (external) | Separate 24-48V PSU |

## DM542T Wiring (per driver)

### Level Shifter Required

The ESP32-S3 outputs 3.3V on GPIO pins. The DM542T optocoupler inputs need 4-5V to trigger
reliably. A **4-channel level shifter** (3.3V → 5V) is required between the board and each driver.

Recommended: BSS138-based 4-channel bidirectional level shifter (3x, one per axis)

Level shifter connections:
- LV (low voltage): 3.3V from board
- HV (high voltage): 5V from board (endstop connector pin 1)
- GND: shared
- LV channels: ESDG signal pins (Step, Dir, Enable)
- HV channels: DM542T inputs (PUL+, DIR+, ENA+)

### Signal Path

```
Board ESDG → Level Shifter (3.3V→5V) → DM542T
```

Each axis has an **ESDG** header in front of the driver sockets for external drivers:

| ESDG Pin | Signal | Level Shifter In | Level Shifter Out | DM542T Terminal | Wire Color |
|---|---|---|---|---|---|
| E | Enable | LV ch1 | HV ch1 | ENA+ | Red |
| S | Step | LV ch2 | HV ch2 | PUL+ | Yellow |
| D | Direction | LV ch3 | HV ch3 | DIR+ | Green |
| G | Ground | GND | GND | ENA-, PUL-, DIR- (common GND) | Black |

4th channel on each level shifter is spare (future: alarm signal from driver).

### DM542T DIP Switch Settings

Motor: NEMA 23, 57x56mm, 3A, 1.8°, 1.2 N.m
Supply: 45V DC
**Signal voltage switch: set to 5V** (not 24V!)

| SW  | Position | Function |
|-----|---|---|
| SW1 | ON | Peak current 2.84A |
| SW2 | ON | |
| SW3 | OFF | |
| SW4 | OFF | Full current at idle  |
| SW5 | OFF | Microstep: 8 (1600 pulse/rev) |
| SW6 | OFF | |
| SW7 | ON | |
| SW8 | ON | |

Result: 8 microsteps → 1600 pulses/rev → 400 steps/mm (with SFU1204, 4mm pitch)

Pulse/Rev table (confirmed for this DM542T version):

| SW5 | SW6 | SW7 | SW8 | Pulse/Rev | Microsteps |
|-----|-----|-----|-----|---|---|
| on  | on  | on  | on  | 200 | 1 |
| off | on  | on  | on  | 400 | 2 |
| on  | off | on  | on  | 800 | 4 |
| off | off | on  | on  | 1600 | 8 |
| on  | on  | off | on  | 3200 | 16 |
| on  | off | off | off | 20000 | 100 |
| off | off | off | off | 25000 | 125 |

### Motor Aviation Connector (GX16-5)

5-pin aviation connector between DM542T and NEMA 23 motor:

| Pin | Signal | DM542T Terminal | Wire Color |
|-----|---|---|---|
| 1 | A+ | A+ | Red |
| 2 | A- | A- | Yellow |
| 3 | GND/Shield | — | Black |
| 4 | B+ | B+ | Blue |
| 5 | B- | B- | Green |

Same pinout and color coding for all 3 axes.

Note: The cable colors are our convention for the interconnect wiring. Motor wire colors vary by
manufacturer — check your motor's datasheet to identify coil pairs and map them to the connector pins.

### Motor Wire to Aviation Connector Mapping

Motor: 57BYG250B-8 (Black=A+, Green=A-, Red=B+, Blue=B-)

| Aviation Pin | Signal | Connector Wire | Motor Wire |
|---|---|---|---|
| 1 | A+ | Red | Black |
| 2 | A- | Yellow | Green |
| 3 | GND | Black | (shield) |
| 4 | B+ | Blue | Red |
| 5 | B- | Green | Blue |

## Probes

### HLTNC 3D Touch Probe (2025 version, USB-C, NPN-NO)

3-wire active probe, requires 5-24V power supply.

| Wire | Signal | DLC32 MAX Connection  |
|---|---|---|
| Red | VCC (5-24V) | 5V (endstop "V" pin) |
| Black  | GND | GND |
| Yellow | Signal (NPN-NO) | Probe connector (gpio.37) |

Triggers LOW when stylus touches workpiece.

### Z Tool Setter (AllyCircle, NC switch, spring-loaded)

Fixed tool setter for repeatable Z referencing after tool changes.
Two internal NC (normally closed) switches: main probe + overtravel alarm.

| Wire | Signal | DLC32 MAX Connection |
|---|---|---|
| Red | Probe (NC) | Flame connector IO36 (S) |
| Black  | Probe GND | Flame connector GND (G) |
| Yellow | Overtravel (NC) | (not connected) |
| Green  | Overtravel GND  | (not connected) |

Config: `toolsetter_pin: gpio.36:high:pu` (triggers when NC switch opens on contact)

Position: X20 Y17.5 (back-left corner of wasteboard)
Probe value: Z=-13.065 (machine coords, double probe at 20mm/min)

### Z Touch Plate (auto-zero, NO switch)

Touch plate for setting Z=0 on the workpiece surface. Place on material, probe down, remove before cutting.
Requires alligator clip connected from plate to tool/collet to complete the circuit.

Shares Probe connector (IO37) with the HLTNC 3D probe — swap as needed.

| Wire | Signal | DLC32 MAX Connection |
|---|---|---|
| + | Signal (NO) | Probe connector IO37 (S) |
| − | GND | Probe connector IO37 (G) |

Config: `probe: pin: gpio.37:low:pu` (same as 3D probe)

Thickness: 19.22mm (measured)

## Pendant (FluidDial) → U1 RJ11 telephone jack

| Function | Pin |
|---|---|
| TX | IO17 |
| RX | IO18 |

Protocol: UART 1000000 baud, 8N1

Note: This connector is shared with the MKS 3.5" touch screen. Use either pendant OR screen, not both.

## Power

- Board input: 12-24V DC, max 10A (DC-007B-2.1mm connector)
- DM542T drivers: 24-48V DC (separate PSU recommended for 3 NEMA 23 motors)
- Logic signals (step/dir/enable) are 3.3V from ESP32-S3, compatible with DM542T optocoupled inputs
- The GND 12-24V connector on the left edge provides GND reference for external driver signal wiring

## Notes

- The board has Y1-MOTOR and Y2-MOTOR connectors for dual-Y setups. We only use Y1.
- Plug/unplug drivers and motors only with power off.
- The RJ11 connector is shared between display and UART pendant — cannot use both simultaneously.
- Door connector (IO38) is kept free for future use as emergency stop or safety door.

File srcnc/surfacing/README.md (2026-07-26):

# surfacing/

Wasteboard surfacing G-code for the SRcnc machine.

Skim pass to flatten the MDF wasteboard and establish a true Z reference plane.
Run this after tramming the spindle, before any precision work.

## Workflow

1. Tram the spindle (dial indicator sweep in X and Y)
2. Home machine (`$H`)
3. Place touch plate on wasteboard, run **UGS macro 2** → sets G54 Z0 at wasteboard surface
4. Remove touch plate
5. Load `surfacing.nc` in UGS, run

## Parameters

| Parameter | Default | Description |
|---|---|---|
| Tool | 20.2mm HSS endmill | Flat 2-flute |
| Stepover | 40% = 8mm | Conservative for good finish |
| Depth | 0.5mm | Single skim pass |
| Feed XY | 2000 mm/min | |
| Feed Z | 200 mm/min | |
| Area | 210×370mm | Centered at machine X110 Y190 |
| Passes | 25 | Boustrophedon (zigzag) |

## Regenerate

```bash
make surfacing.nc

# Custom depth or feed
python3 surfacing.py --depth 1.0 --feed 1500 > surfacing.nc
```

## Notes

- Uses G53 (machine coordinates) for XY — no workpiece setup needed
- Uses G54 Z from touch plate probe — must probe Z before running
- Z0 = wasteboard surface as measured by touch plate
- Cuts at Z=-0.5 (or `--depth` value)
- After surfacing, re-probe Z before any subsequent job

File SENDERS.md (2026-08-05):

# G-code Senders

Configuration for the SRcnc machine.

## Active: gSender (Flexi-HAL / grblHAL)

### Connection

| Method | Address | Notes |
|---|---|---|
| USB serial | `/dev/cnc` @ 115200 baud | Udev symlink to STM32 CDC (ttyACM0) |

### Setup

```bash
# Config symlinked from ~/.config/gSender → gsender/
gsender  # launch
```

### Settings

- Firmware: **grblHAL**
- Port: `/dev/cnc`
- Baud: **115200**
- Units: **mm**
- Safe retract height: **15mm**
- Machine profile: SRcnc (220×380×95mm)

### Macros

Source of truth: [`gsender/macros.json`](gsender/macros.json)

| # | Name | G-code |
|---|---|---|
| 1 | Go to XY zero | `G90 G0 X0 Y0` |
| 2 | Probe Z (touch plate) | `G91 G38.2 Z-30 F100; G0 Z2; G38.2 Z-5 F20; G90 G10 L20 P1 Z19.25; G0 Z25` |
| 3 | Load Workpiece | `G90 G53 G0 Z0; G53 G0 X-218 Y0` |
| 4 | Park | `G90 G53 G0 Z0; G53 G0 X-218 Y-378` |
| 5 | Tool Change | `G90 G53 G0 Z0; G53 G0 X-110 Y-378` |
| 6 | Center | `G90 G53 G0 Z0; G53 G0 X-110 Y-190` |

### Probe Z workflow
1. Jog spindle to within 30mm above the touch plate
2. Place touch plate on workpiece surface
3. Clip ground wire to bit
4. Run macro 2
5. Wait for Z to lift clear, then remove touch plate
6. G54 Z0 is now at workpiece surface (plate thickness: 19.25mm)

### Machine Coordinates

After homing (`$H`): X=0, Y=0, Z=0 at home switches.
Travel is in the **negative** direction:
- X: 0 to -220 (right)
- Y: 0 to -380 (back)
- Z: 0 to -95 (down)

## Legacy: UGS (FluidNC / MKS DLC32 MAX)

### Connection

| Method | Address | Notes |
|---|---|---|
| USB serial | `/dev/cnc` @ 115200 baud | Udev symlink to CH340 (ttyUSB0) |
| WiFi | `fluidnc.home:80` (WebSocket) | TCPDriver, port `fluidnc.home`, baud `23` |

### Setup

```bash
make setup   # symlink ugs/ → ~/.config/ugs
make ugs     # launch UGS
```

### Settings

- Firmware: **FluidNC**
- Connection driver: **JSERIALCOMM**
- Port: **cnc**
- Baud: **115200**

### Macros

Same as gSender (macros 1-6 above).

## Machine Parameters

| Parameter | X | Y | Z |
|---|---|---|---|
| Steps/mm | 400 | 400 | 400 |
| Max rate (mm/min) | 3000 | 3000 | 1000 |
| Acceleration (mm/s²) | 100 | 100 | 50 |
| Max travel (mm) | 220 | 380 | 95 |
| Homing direction | -X | -Y | +Z |

Spindle: 0–12000 RPM (manual router, no VFD)

## Top Panel Setup (pedalboard case)

Scripts live in the `pedalboard-case` repo under `cnc/`.
The sender must be disconnected before running (scripts own the serial port).

### 1. Cut holes — probe-setup.py

```bash
cd /path/to/pedalboard-case/cnc
make install          # first time only (pip install pyserial)
python3 probe-setup.py
```

Steps: home → install 3D probe → spoilboard Z ref → 5 edge probes (centre +
angle) → per-feature Z at 12 points → swap to cutting tool → touch plate Z →
generate `top-panel.nc`.

```bash
# Then in gSender: load top-panel.nc, dial 1, WD-40, run at 150% feed
```

### 2. Engrave labels — engrave-setup.py

Runs independently — no need to run probe-setup.py first.

```bash
python3 engrave-setup.py
```

Steps: home → install 3D probe → spoilboard Z ref → 5 edge probes (centre +
angle) → 6×10 surface height map (38 points, skips all holes) → generate
`engraving.nc` via plates.py → swap to V-bit → touch plate Z.

```bash
# Then in gSender: load engraving.nc, run
```

Options:
```bash
python3 probe-setup.py --dry-run           # print commands without connecting
python3 engrave-setup.py --dry-run
python3 probe-setup.py --port /tmp/cnc-sim # test with simulator
python3 engrave-setup.py --port /tmp/cnc-sim
```

### Testing with simulator

```bash
# Terminal 1 — start simulator
python3 mock-machine.py --angle 0.3 --crown 0.3

# Terminal 2 — run setup
python3 probe-setup.py --port /tmp/cnc-sim
python3 engrave-setup.py --port /tmp/cnc-sim

# Or use the test runner:
make test           # probe-setup against simulator
make test-engrave   # engrave-setup with 0.3mm crown
```

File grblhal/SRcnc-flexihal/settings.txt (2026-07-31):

; SRcnc grblHAL settings for Flexi-HAL
; Apply after firmware flash: cat settings.txt | grep -v '^;' | grep -v '^$' > /dev/cnc
; Or send line by line in gSender console

; Steps/mm
$100=400.000
$101=400.000
$102=400.000

; Max rate mm/min
$110=3000.000
$111=3000.000
$112=1000.000

; Acceleration mm/s²
$120=100.000
$121=100.000
$122=50.000

; Max travel mm
$130=220.000
$131=380.000
$132=95.000

; Limit switches (NO, inverted)
$5=7

; Probe pin invert (NO probes, inverted)
$6=1

; Soft limits
$20=1

; Hard limits
$21=1

; Homing enabled + set machine origin to 0 after homing
; Bit 0: Enable, Bit 1: Single axis commands, Bit 3: Set machine origin to 0
; After homing: MPos = 0,0,0; X/Y travel positive, Z travel negative
$22=11

; Homing direction invert mask
; X and Y inverted (due to $3 direction inversion interactions)
; Z homes to max naturally
$23=3

; Homing feed rate mm/min
$24=25.000

; Homing seek rate mm/min
$25=500.000

; Homing debounce ms
$26=250

; Homing pull-off mm
$27=2.000

; Spindle max RPM
$30=12000

; Spindle min RPM
$31=0

; Step idle delay ms (255 = never disable)
$1=255

; Invert step enable (active-high for DM542T)
$4=1

; Direction invert mask (X=1, Z=4 → 5)
$3=5

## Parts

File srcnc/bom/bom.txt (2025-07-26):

Vitamins:
 F     X  Y  Z
 r  M  a  a  a
 a  a  x  x  x
 m  i  i  i  i
 e  n  s  s  s
  |  | 1| 1| 1|  3 Stepper motor NEMA22 x 51.2mm (6.35x24 shaft)
  |  | 1| 1|  |  2 BK10 fixed ball screw support
  |  | 1| 1|  |  2 BF10 floating ball screw support
  |  | 1| 1|  |  2 Leadscrew Nut for SFU1204
  |  | 1|  |  |  1 Leadscrew 12 x 350mm, 4mm lead, 1 starts
  |  |  | 1|  |  1 Leadscrew 12 x 550mm, 4mm lead, 1 starts
  |  |  |  | 1|  1 SGX_5080 linear guide table
  |  |16|24|  | 40 Nut M4 x 3.2mm 
  |  | 6| 6|  | 12 Nut M5 x 4mm 
  |  | 1| 1|  |  2 Leadscrew Nut Housing
  |  | 4| 4|  |  8 SBR12UU bearing block
  |  | 2|  |  |  2 SBR12 rail, length 350mm
  |  |  | 2|  |  2 SBR12 rail, length 550mm
  |  | 6| 6|  | 12 Screw M4 cap x 15mm
  |  |  |24|  | 24 Screw M4 cap x 25mm
  |  |16|  |  | 16 Screw M4 cap x 50mm
  |  |16|16|  | 32 Screw M5 cap x 16mm
  |  |  | 6|  |  6 Screw M5 cap x 47.5mm
  |  | 6|  |  |  6 Screw M5 cap x 72.5mm
  | 4|  |  |  |  4 Screw M6 cap x 20mm
16|  |  |  |  | 16 Screw M6 cap x 55mm
  |  | 1| 1| 1|  3 Shaft coupling SC_8x8_flex
  |  | 1|  |  |  1 Chipboard 360mm x 200mm x 40mm
 1|  |  |  |  |  1 Chipboard 360mm x 580mm x 40mm
 2|  |  |  |  |  2 Chipboard 400mm x 360mm x 40mm
  |  |  | 1|  |  1 Sheet MDF 356mm x 580mm x 15mm
  |  | 1|  |  |  1 Sheet MDF 80mm x 200mm x 15mm
  |  |  | 1|  |  1 Sheet MDF 400mm x 240mm x 18mm
16| 4|  |  |  | 20 Threaded insert M6 x 15mm
  |  |16|24|  | 40 Washer  M4 x 9mm x 0.8mm
  |  | 6| 6|  | 12 Washer  M5 x 10mm x 1mm
16| 4|  |  |  | 20 Washer  M6 x 12.5mm x 1.5mm

Printed:
  |  | 1| 1|  |  2 nut_housing_adapter.stl
  |  |  | 1|  |  1 waste_board.stl
  |  | 1|  |  |  1 zplate.stl

CNC cut:
 1|  |  |  |  |  1 frame_bottom_side.dxf
 1|  |  |  |  |  1 frame_left_side.dxf
 1|  |  |  |  |  1 frame_right_side.dxf
  |  | 1|  |  |  1 xplate.dxf
  |  |  | 1|  |  1 yplate.dxf

Assemblies:
  1 Frame_assembly
  1 main_assembly
  1 xaxis_assembly
  1 yaxis_assembly
  1 zaxis_assembly

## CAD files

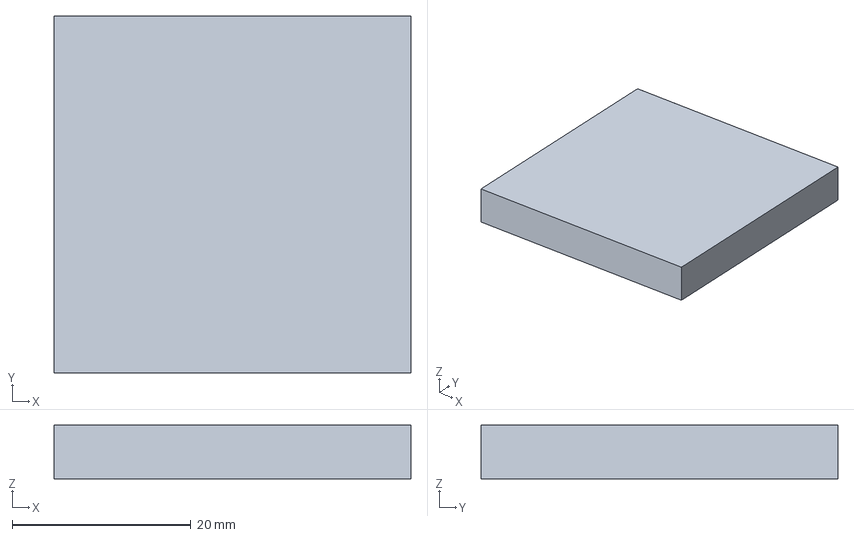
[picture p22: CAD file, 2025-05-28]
parts/calibrate/calibrate.FCStd
40.0 x 40.0 x 6.00 mm

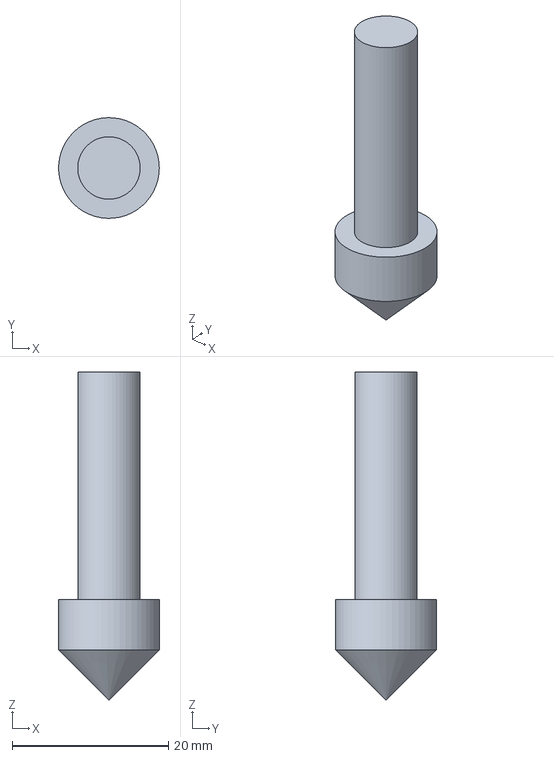
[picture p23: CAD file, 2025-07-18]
parts/coffee-time/Coffee-Time.FCStd
12.9 x 12.9 x 42.0 mm

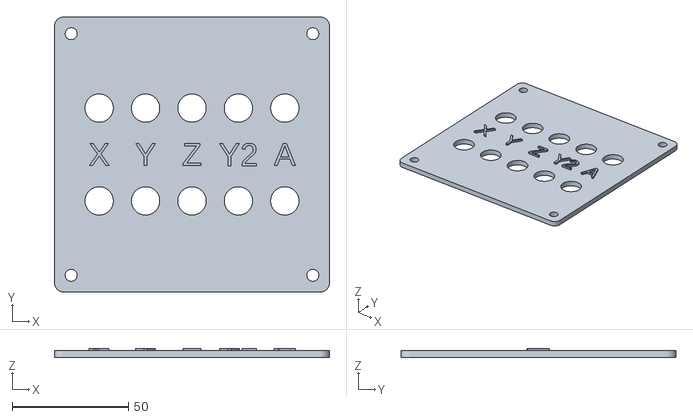
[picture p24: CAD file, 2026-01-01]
parts/dc-plate/dc-plate.stl
118.5 x 118.5 x 4.00

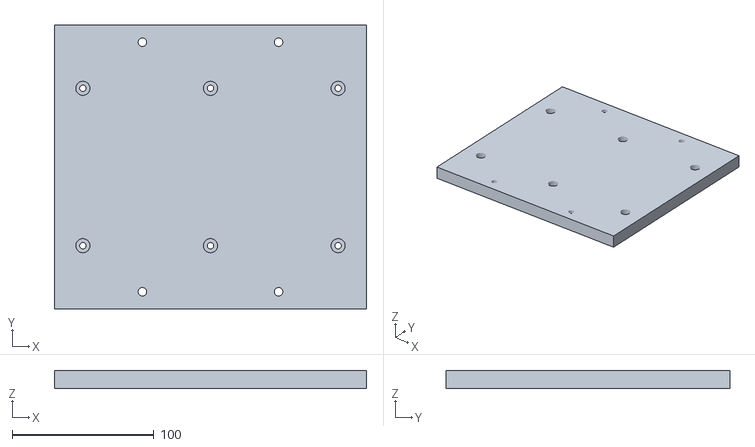
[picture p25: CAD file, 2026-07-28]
parts/fixture-plate/fixture-plate.stl
220.0 x 200.0 x 12.7

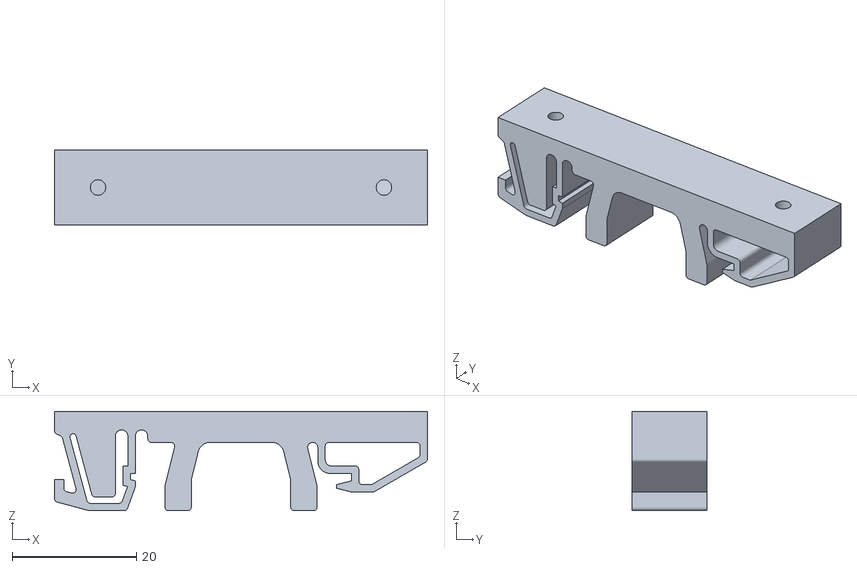
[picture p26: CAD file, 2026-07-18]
parts/flexi-hal/DIN_Clip.stl
60.0 x 12.0 x 16.0

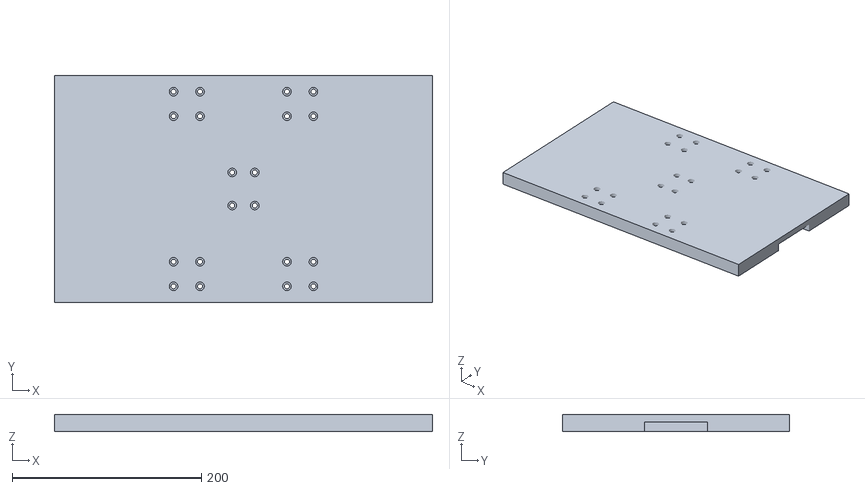
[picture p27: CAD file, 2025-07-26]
srcnc/stls/waste_board.stl
400.0 x 240.0 x 18.0

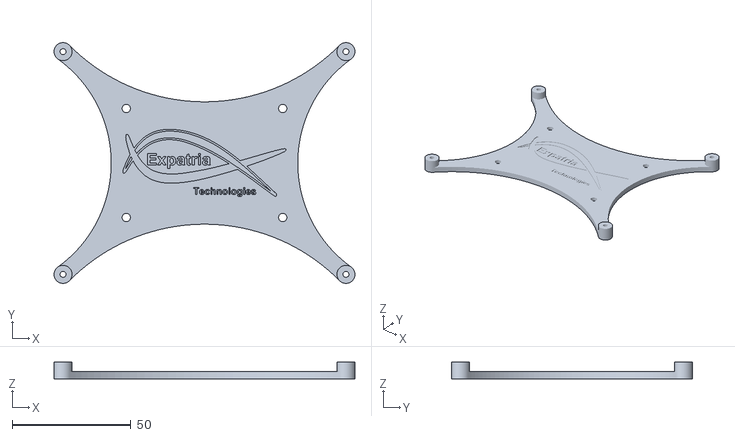
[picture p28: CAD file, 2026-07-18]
parts/flexi-hal/Flexi-HAL_Mount_Plate.stl
127.0 x 101.6 x 7.00

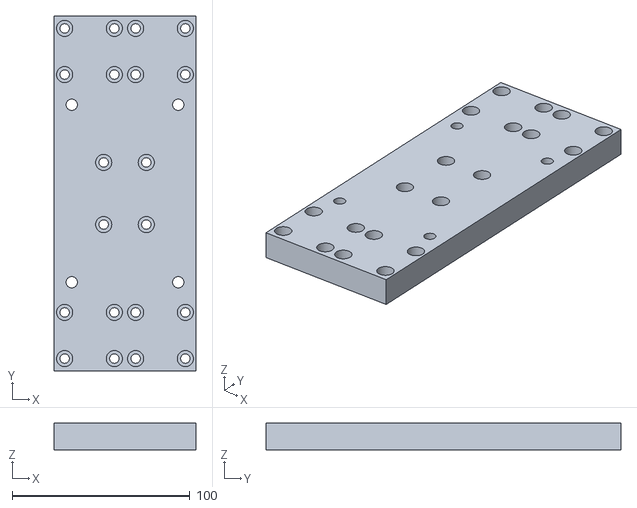
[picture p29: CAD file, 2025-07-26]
srcnc/stls/zplate.stl
80.0 x 200.0 x 15.0

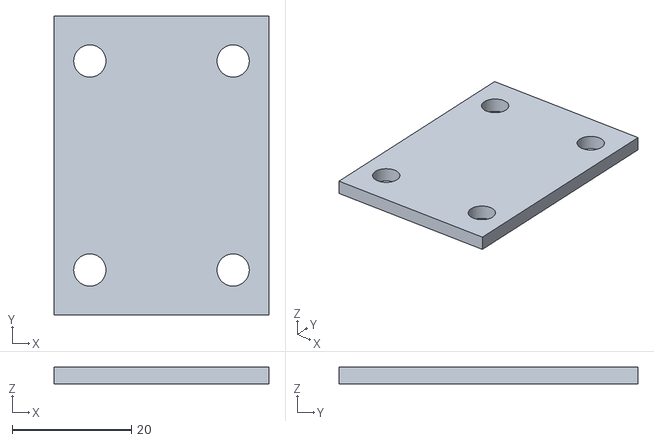
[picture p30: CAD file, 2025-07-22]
srcnc/stls/nut_housing_adapter.stl
36.0 x 50.0 x 2.80

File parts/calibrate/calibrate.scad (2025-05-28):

difference()
{
    cube([ 40, 40, 6 ], center = true);
    translate([ 0, 0, 2 ]) cylinder(r = 10, h = 2, center = true);
    translate([ 0, 0, 2.5 ]) cube([ 30, 30, 1 ], center = true);
}

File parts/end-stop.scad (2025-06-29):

include <BOSL2/screws.scad>
include <BOSL2/std.scad>

$fn = 100;

difference()
{
    cuboid([ 16, 80, 12 ], anchor = [ 0, 0 ], rounding = 1, edges = "Z");
    fwd(20) cuboid([ 6.2, 27, 14 ], anchor = [ 0, 0 ], rounding = 3);
    back(15) cuboid([ 6.2, 27, 14 ], anchor = [ 0, 0 ], rounding = 3);
    fwd(5) up(3) cube([ 25, 72, 10 ], anchor = [ 0, 0 ]);
}

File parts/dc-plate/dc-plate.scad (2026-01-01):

include <BOSL2/std.scad>

$fn = 100;

axis = [ [ -2, "X" ], [ -1, "Y" ], [ 0, "Z" ], [ 1, "Y2" ], [ 2, "A" ] ];

difference()
{
    union()
    {
        cuboid([ 118.5, 118.5, 3 ], anchor = [ 0, 0 ], rounding = 4, edges = "Z");
        for (a = axis)
        {
            translate([ 20 * a[0], 0, 1.5 ]) linear_extrude(1) text(a[1], halign = "center", valign = "center");
        }
    }
    for (x = [ -1, 1 ], y = [ -1, 1 ])
    {
        translate([ x * 52.05, y * 52.05 ]) cylinder(d = 5.2, h = 10, center = true);
    }
    for (x = [-2:2], y = [ -1, 1 ])
    {
        translate([ x * 20, y * 20 ]) cylinder(d = 12.2, h = 10, center = true);
    }
}

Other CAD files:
srcnc/dxfs/yplate.dxf
srcnc/dxfs/xplate.dxf
srcnc/dxfs/frame_right_side.dxf
srcnc/dxfs/frame_left_side.dxf
srcnc/dxfs/frame_bottom_side.dxf
parts/end-stop/end-stop.scad
parts/fixture-plate/fixture-plate.scad
srcnc/scad/ball_screw_support.scad
srcnc/scad/ball_screw_supports.scad
srcnc/scad/linear_guide_table.scad
srcnc/scad/linear_guide_tables.scad
srcnc/scad/main.scad
srcnc/scad/test.scad

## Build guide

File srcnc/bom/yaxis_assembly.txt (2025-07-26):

yaxis_assembly:
Vitamins:
  1 Stepper motor NEMA22 x 51.2mm (6.35x24 shaft)
  1 BK10 fixed ball screw support
  1 BF10 floating ball screw support
  1 Leadscrew Nut for SFU1204
  1 Leadscrew 12 x 550mm, 4mm lead, 1 starts
 24 Nut M4 x 3.2mm 
  6 Nut M5 x 4mm 
  1 Leadscrew Nut Housing
  4 SBR12UU bearing block
  2 SBR12 rail, length 550mm
  6 Screw M4 cap x 15mm
 24 Screw M4 cap x 25mm
 16 Screw M5 cap x 16mm
  6 Screw M5 cap x 47.5mm
  1 Shaft coupling SC_8x8_flex
  1 Sheet MDF 356mm x 580mm x 15mm
  1 Sheet MDF 400mm x 240mm x 18mm
 24 Washer  M4 x 9mm x 0.8mm
  6 Washer  M5 x 10mm x 1mm

Printed:
  1 nut_housing_adapter.stl
  1 waste_board.stl

CNC cut:
  1 yplate.dxf

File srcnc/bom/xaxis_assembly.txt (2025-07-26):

xaxis_assembly:
Vitamins:
  1 Stepper motor NEMA22 x 51.2mm (6.35x24 shaft)
  1 BK10 fixed ball screw support
  1 BF10 floating ball screw support
  1 Leadscrew Nut for SFU1204
  1 Leadscrew 12 x 350mm, 4mm lead, 1 starts
 16 Nut M4 x 3.2mm 
  6 Nut M5 x 4mm 
  1 Leadscrew Nut Housing
  4 SBR12UU bearing block
  2 SBR12 rail, length 350mm
  6 Screw M4 cap x 15mm
 16 Screw M4 cap x 50mm
 16 Screw M5 cap x 16mm
  6 Screw M5 cap x 72.5mm
  1 Shaft coupling SC_8x8_flex
  1 Chipboard 360mm x 200mm x 40mm
  1 Sheet MDF 80mm x 200mm x 15mm
 16 Washer  M4 x 9mm x 0.8mm
  6 Washer  M5 x 10mm x 1mm

Printed:
  1 nut_housing_adapter.stl
  1 zplate.stl

CNC cut:
  1 xplate.dxf

Assemblies:
  1 zaxis_assembly

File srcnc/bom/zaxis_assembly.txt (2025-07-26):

zaxis_assembly:
Vitamins:
  1 Stepper motor NEMA22 x 51.2mm (6.35x24 shaft)
  1 SGX_5080 linear guide table
  1 Shaft coupling SC_8x8_flex

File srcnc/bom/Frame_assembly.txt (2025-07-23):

Frame_assembly:
Vitamins:
 16 Screw M6 cap x 55mm
  1 Chipboard 360mm x 580mm x 40mm
  2 Chipboard 400mm x 360mm x 40mm
 16 Threaded insert M6 x 15mm
 16 Washer  M6 x 12.5mm x 1.5mm

CNC cut:
  1 frame_bottom_side.dxf
  1 frame_left_side.dxf
  1 frame_right_side.dxf

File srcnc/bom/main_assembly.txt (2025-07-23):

main_assembly:
Vitamins:
  4 Screw M6 cap x 20mm
  4 Threaded insert M6 x 15mm
  4 Washer  M6 x 12.5mm x 1.5mm

Assemblies:
  1 Frame_assembly
  1 xaxis_assembly
  1 yaxis_assembly

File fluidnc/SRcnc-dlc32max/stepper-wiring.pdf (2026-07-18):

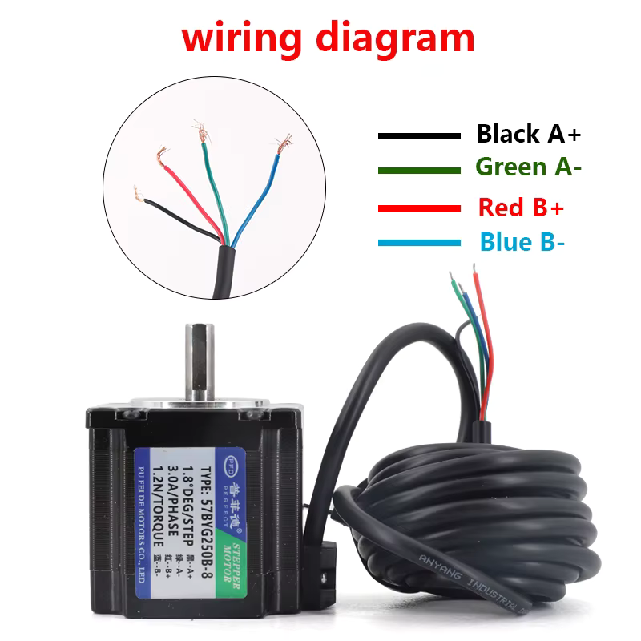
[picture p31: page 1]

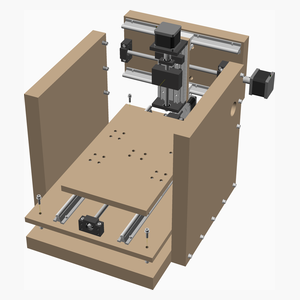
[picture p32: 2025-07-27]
srcnc/assemblies/main_assembly_tn.png

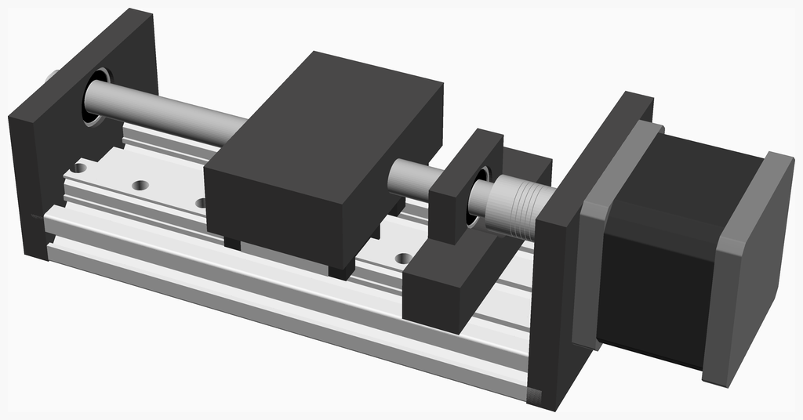
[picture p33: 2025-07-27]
srcnc/assemblies/zaxis_assembled.png

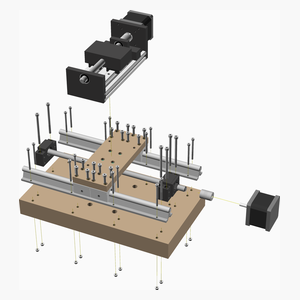
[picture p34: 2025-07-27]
srcnc/assemblies/xaxis_assembly_tn.png

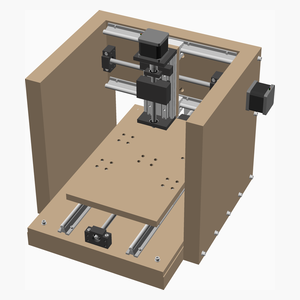
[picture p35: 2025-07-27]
srcnc/assemblies/main_assembled_tn.png

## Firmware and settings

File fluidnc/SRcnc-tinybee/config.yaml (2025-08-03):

board: MKS TinyBee V1.0
name: SRcnc

kinematics:
  Cartesian:

i2so:
  bck_pin: gpio.25
  data_pin: gpio.27
  ws_pin: gpio.26

spi:
  miso_pin: gpio.19
  mosi_pin: gpio.23
  sck_pin: gpio.18

sdcard:
  cs_pin: gpio.5
  # uses TH2 IO34 active low - MAKE SURE jumper J2 is set to SDDET!!!
  card_detect_pin: gpio.34:low

# Pendant
uart1:
  # EXP2 Pin 5 (yellow)
  txd_pin: gpio.12
  # EXP2 Pin 3 (blue)
  rxd_pin: gpio.14
  rts_pin: NO_PIN
  cts_pin: NO_PIN
  baud: 1000000
  mode: 8N1

# TMC-2209 drivers
uart2:
  txd_pin: gpio.17
  rxd_pin: gpio.16
  baud: 115200
  mode: 8N1

uart_channel1:
  report_interval_ms: 75
  uart_num: 1

stepping:
  engine: I2S_STATIC
  idle_ms: 255
  pulse_us: 4
  dir_delay_us: 1
  disable_delay_us: 2

axes:
  x:
    steps_per_mm: 400.000
    max_rate_mm_per_min: 800.000
    acceleration_mm_per_sec2: 20.000
    max_travel_mm: 220.000
    soft_limits: true
    homing:
      cycle: 2
      positive_direction: false
      mpos_mm: 0.000
      feed_mm_per_min: 300.000
      seek_mm_per_min: 500.000
      settle_ms: 500
      seek_scaler: 1.100
      feed_scaler: 1.100

    motor0:
      limit_pos_pin: gpio.33:low:pu
      hard_limits: true
      pulloff_mm: 2.000
      tmc_2209:
        uart_num: 2
        addr: 0
        cs_pin: NO_PIN
        r_sense_ohms: 0.110
        run_amps: 1.300
        hold_amps: 0.500
        microsteps: 8
        stallguard: 0
        stallguard_debug: false
        toff_disable: 0
        toff_stealthchop: 5
        toff_coolstep: 3
        run_mode: StealthChop
        homing_mode: StealthChop
        homing_amps: 0.50
        use_enable: false
        step_pin: I2SO.1
        direction_pin: I2SO.2
        disable_pin: I2SO.0

    # use E0 driver for 2nd X axis motor
  #    motor1:
  #      hard_limits: true
  #      pulloff_mm: 2.000
  #      stepstick:
  #        step_pin: I2SO.10
  #        direction_pin: I2SO.11
  #        disable_pin: I2SO.9

  y:
    steps_per_mm: 400.000
    max_rate_mm_per_min: 800.000
    acceleration_mm_per_sec2: 20.000
    max_travel_mm: 380.000
    soft_limits: true
    homing:
      cycle: 3
      positive_direction: false
      mpos_mm: 0.000
      feed_mm_per_min: 300.000
      seek_mm_per_min: 500.000
      settle_ms: 500
      seek_scaler: 1.100
      feed_scaler: 1.100

    motor0:
      limit_neg_pin: gpio.32:low:pu
      hard_limits: true
      pulloff_mm: 2.000
      tmc_2209:
        uart_num: 2
        addr: 1
        cs_pin: NO_PIN
        r_sense_ohms: 0.110
        run_amps: 1.300
        hold_amps: 0.500
        microsteps: 8
        stallguard: 0
        stallguard_debug: false
        toff_disable: 0
        toff_stealthchop: 5
        toff_coolstep: 3
        run_mode: StealthChop
        homing_mode: StealthChop
        homing_amps: 0.50
        use_enable: false
        step_pin: I2SO.4
        direction_pin: I2SO.5:low
        disable_pin: I2SO.3

    # use E1 driver for 2nd Y axis motor
  #    motor1:
  #      limit_neg_pin: NO_PIN
  #      hard_limits: false
  #      pulloff_mm: 4.000
  #      stepstick:
  #        step_pin: I2SO.13
  #        direction_pin: I2SO.14
  #        disable_pin: I2SO.12

  z:
    steps_per_mm: 400.000
    max_rate_mm_per_min: 400.000
    acceleration_mm_per_sec2: 20.000
    max_travel_mm: 95.000
    soft_limits: true
    homing:
      cycle: 1
      positive_direction: true
      mpos_mm: 0.000
      feed_mm_per_min: 300.000
      seek_mm_per_min: 500.000
      settle_ms: 500
      seek_scaler: 1.100
      feed_scaler: 1.100

    motor0:
      limit_pos_pin: gpio.22:low:pu
      hard_limits: true
      pulloff_mm: 3.000
      tmc_2209:
        uart_num: 2
        addr: 2
        cs_pin: NO_PIN
        r_sense_ohms: 0.110
        run_amps: 1.300
        hold_amps: 0.500
        microsteps: 8
        stallguard: 0
        stallguard_debug: false
        toff_disable: 0
        toff_stealthchop: 5
        toff_coolstep: 3
        run_mode: StealthChop
        homing_mode: StealthChop
        homing_amps: 0.50
        use_enable: false
        step_pin: I2SO.7
        direction_pin: I2SO.8
        disable_pin: I2SO.6

control:
  safety_door_pin: NO_PIN
  # on MT_DET connector
  reset_pin: gpio.35:low
  # on TH1 connector
  feed_hold_pin: gpio.36:low
  # on TB connector
  cycle_start_pin: gpio.39:low
  macro0_pin: NO_PIN
  macro1_pin: NO_PIN
  macro2_pin: NO_PIN
  macro3_pin: NO_PIN

coolant:
  # Heated Bed Terminal Block
  flood_pin: i2so.16
  # HE0 Terminal Block
  mist_pin: i2so.17
  delay_ms: 0

# spindle PWM signal
PWM:
  pwm_hz: 2500
  # on EXP1 IO15 connector.
  # note IO15 will give some short pulses on boot, which may activate spindle
  # use IO17 on EXP1 to avoid
  output_pin: gpio.15:high
  s0_with_disable: true
  tool_num: 0
  spinup_ms: 4000
  spindown_ms: 4000
  speed_map: 0=0.000% 12000=100.000%

Laser:
  pwm_hz: 5000
  # on 3D Touch connector (has pdwn + PWM)
  output_pin: gpio.2:high:pd
  s0_with_disable: true
  tool_num: 1
  speed_map: 0=0.000% 1000=100.000%

start:
  must_home: false

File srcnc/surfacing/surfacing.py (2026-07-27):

#!/usr/bin/env python3
"""
Generate G-code for surfacing the SRcnc wasteboard.

Skim pass to flatten the MDF wasteboard and establish a true Z reference.
Run this after tramming the spindle.

Origin: machine center X110 Y190, Z0 = current wasteboard surface.
Uses G53 machine coordinates — no workpiece setup needed, just home the machine.

Usage:
    python3 surfacing.py > surfacing.nc
    python3 surfacing.py --depth 0.3 --feed 1500 > surfacing.nc
"""

import argparse
import math


def parse_args():
    p = argparse.ArgumentParser(description="Wasteboard surfacing G-code generator")
    p.add_argument("--tool-dia", type=float, default=20.2,
                   help="Endmill diameter in mm (default: 20.2)")
    p.add_argument("--stepover", type=float, default=0.4,
                   help="Stepover as fraction of tool diameter (default: 0.4)")
    p.add_argument("--depth", type=float, default=0.5,
                   help="Depth of cut in mm (default: 0.5)")
    p.add_argument("--feed", type=float, default=2000,
                   help="Feed rate in mm/min (default: 2000)")
    p.add_argument("--feed-z", type=float, default=200,
                   help="Plunge feed rate in mm/min (default: 200)")
    p.add_argument("--spindle-rpm", type=int, default=10000,
                   help="Spindle speed in RPM (default: 10000)")
    p.add_argument("--width", type=float, default=210,
                   help="Surfacing width in mm (default: 210, X axis)")
    p.add_argument("--length", type=float, default=370,
                   help="Surfacing length in mm (default: 370, Y axis)")
    p.add_argument("--safe-z", type=float, default=5.0,
                   help="Safe Z height in mm (default: 5.0)")
    return p.parse_args()


def generate(args):
    tool_r = args.tool_dia / 2.0
    stepover_mm = args.tool_dia * args.stepover

    # Machine center
    cx = 110.0
    cy = 190.0

    # Surfacing area — tool center range
    # Start at 0.2mm from machine zero so tool center is just inside limits
    # Cutting edge extends tool_r past the edge, covering the full wasteboard
    x_min = 0.2
    x_max = cx * 2 - 0.2   # = 219.8mm
    y_min = 0.2
    y_max = cy * 2 - 0.2   # = 379.8mm

    # Toolpath — x_min/y_min are tool center positions directly
    y_start = y_min
    y_end   = y_max
    x_start = x_min
    x_end   = x_max

    # Number of passes along X
    n_passes = math.ceil((x_end - x_start) / stepover_mm) + 1
    actual_stepover = (x_end - x_start) / max(n_passes - 1, 1)

    lines = []
    def emit(line=""):
        lines.append(line)

    emit(f"(Wasteboard surfacing — SRcnc)")
    emit(f"(Tool: {args.tool_dia}mm endmill, {args.stepover*100:.0f}% stepover = {stepover_mm:.1f}mm)")
    emit(f"(Area: full machine travel {cx*2:.0f}x{cy*2:.0f}mm in G53 coords)")
    emit(f"(Depth: {args.depth}mm, Feed: {args.feed}mm/min)")
    emit(f"(Passes: {n_passes}, actual stepover: {actual_stepover:.2f}mm)")
    emit(f"(Precondition: probe Z with touch plate on wasteboard before running)")
    emit(f"(  G54 Z0 = wasteboard surface, XY in machine coords via G53)")
    emit()
    emit("G21 (mm)")
    emit("G90 (absolute)")
    emit()
    emit(f"M3 S{args.spindle_rpm}")
    emit("G4 P2 (spindle spin-up)")
    emit()

    # Move to start position
    emit(f"G53 G0 Z0")
    emit(f"G53 G0 X{x_start:.3f} Y{y_start:.3f}")
    emit(f"G1 Z-{args.depth:.3f} F{args.feed_z} (cut depth relative to probed wasteboard surface)")
    emit()

    # Boustrophedon (zigzag) passes along Y, stepping in X
    for i in range(n_passes):
        x = x_start + i * actual_stepover
        if i % 2 == 0:
            y_from, y_to = y_start, y_end
        else:
            y_from, y_to = y_end, y_start

        if i == 0:
            emit(f"G53 G1 Y{y_to:.3f} F{args.feed}")
        else:
            emit(f"G53 G1 X{x:.3f} F{args.feed}  (pass {i+1}/{n_passes})")
            emit(f"G53 G1 Y{y_to:.3f} F{args.feed}")

    emit()
    emit(f"G0 Z{args.safe_z} (retract to safe height)")
    emit(f"G53 G0 Z0")
    emit("M5")
    emit("G53 G0 X0 Y0")
    emit("M2")

    return "\n".join(lines)


if __name__ == "__main__":
    args = parse_args()
    print(generate(args))

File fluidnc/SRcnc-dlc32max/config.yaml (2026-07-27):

board: MKS DLC32 MAX V1.1
name: SRcnc
meta: 2026-07-12 DLC32 MAX V1.1 (ESP32-S3) with DM542T drivers

kinematics:
  Cartesian:

stepping:
  engine: RMT
  idle_ms: 255
  pulse_us: 4
  dir_delay_us: 1
  disable_delay_us: 2

# Pendant (RJ11/RJ12 telephone jack)
uart1:
  txd_pin: gpio.17
  rxd_pin: gpio.18
  rts_pin: NO_PIN
  cts_pin: NO_PIN
  baud: 1000000
  mode: 8N1

uart_channel1:
  report_interval_ms: 75
  uart_num: 1

spi:
  miso_pin: gpio.12
  mosi_pin: gpio.14
  sck_pin: gpio.13

sdcard:
  cs_pin: NO_PIN
  card_detect_pin: NO_PIN

axes:
  shared_stepper_disable_pin: gpio.8

  x:
    steps_per_mm: 400.000
    max_rate_mm_per_min: 3000.000
    acceleration_mm_per_sec2: 100.000
    max_travel_mm: 220.000
    soft_limits: true
    homing:
      cycle: 2
      positive_direction: false
      mpos_mm: 0.000
      feed_mm_per_min: 300.000
      seek_mm_per_min: 500.000
      settle_ms: 500
      seek_scaler: 1.100
      feed_scaler: 1.100

    motor0:
      limit_neg_pin: gpio.39:low:pu
      hard_limits: true
      pulloff_mm: 2.000
      stepstick:
        step_pin: gpio.16
        direction_pin: gpio.15:low

  y:
    steps_per_mm: 400.000
    max_rate_mm_per_min: 3000.000
    acceleration_mm_per_sec2: 100.000
    max_travel_mm: 380.000
    soft_limits: true
    homing:
      cycle: 3
      positive_direction: false
      mpos_mm: 0.000
      feed_mm_per_min: 300.000
      seek_mm_per_min: 500.000
      settle_ms: 500
      seek_scaler: 1.100
      feed_scaler: 1.100

    motor0:
      limit_neg_pin: gpio.40:low:pu
      hard_limits: true
      pulloff_mm: 2.000
      stepstick:
        step_pin: gpio.7
        direction_pin: gpio.6

  z:
    steps_per_mm: 400.000
    max_rate_mm_per_min: 1000.000
    acceleration_mm_per_sec2: 50.000
    max_travel_mm: 95.000
    soft_limits: true
    homing:
      cycle: 1
      positive_direction: true
      mpos_mm: 0.000
      feed_mm_per_min: 300.000
      seek_mm_per_min: 500.000
      settle_ms: 500
      seek_scaler: 1.100
      feed_scaler: 1.100

    motor0:
      limit_pos_pin: gpio.41:low:pu
      hard_limits: true
      pulloff_mm: 3.000
      stepstick:
        step_pin: gpio.5
        direction_pin: gpio.4:low

control:
  safety_door_pin: NO_PIN
  reset_pin: NO_PIN
  feed_hold_pin: NO_PIN
  cycle_start_pin: NO_PIN
  macro0_pin: NO_PIN
  macro1_pin: NO_PIN
  macro2_pin: NO_PIN
  macro3_pin: NO_PIN

probe:
  # Probe input (IO37) — shared by HLTNC 3D Touch Probe and Z touch plate
  # Swap connector when switching between the two
  pin: gpio.37:low:pu
  check_mode_start: true

coolant:
  flood_pin: NO_PIN
  mist_pin: NO_PIN
  delay_ms: 0

# spindle PWM signal
PWM:
  pwm_hz: 2500
  output_pin: gpio.2:high
  enable_pin: gpio.35
  s0_with_disable: true
  tool_num: 0
  spinup_ms: 4000
  spindown_ms: 4000
  speed_map: 0=0.000% 12000=100.000%

start:
  must_home: false

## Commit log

2025-05-20 XY axis configuration
    [config.yaml]
2025-05-20 XYZ axis configuration
    [config.yaml]
2025-05-28 My fist calibration cnc job
    [calibrate.FCStd, calibrate.scad]
2025-05-31 change x direction
    [config.yaml]
2025-06-03 Add Fluiddial
    [Engrave.FCStd]
2025-06-08 Add Pendant USART
    [config.yaml]
2025-06-09 Improve Makefile
    [config.yaml]
2025-06-09 Change Pendant UART to EXP port
    [config.yaml]
2025-06-09 Rename tinybee config folder
    [config.yaml]
2025-06-15 Use TMC-2209 drivers
    [config.yaml]
2025-06-15 Add new part
    [Engrave.FCStd]
2025-06-15 Add traming plate
    [tramming.scad]
2025-06-15 Add dial tool
    [dial.scad]
2025-06-15 Improv dial jig
    [dial.scad, tramming.scad]
2025-06-16 add comments
    [dial.scad]
2025-06-17 Also add the nut housing screws
    [tramming.scad]
2025-06-17 use standard m5 screws
    [tramming.scad]
2025-06-17 longer screws
    [tramming.scad]
2025-06-18 Fix sbr12 dimensions
    [tramming.scad]
2025-06-20 Add tramming adapter
    [tramming-adapter.scad]
2025-06-20 Fix thickness
    [tramming-adapter.scad, tramming-plate.scad]
2025-06-20 Z axis mount is M6
    [tramming-plate.scad]
2025-06-28 Add correction factor to tramming adapter
    [tramming-adapter.scad]
2025-06-29 Add End-Stop
    [end-stop.scad]
2025-06-29 Improve end stop
    [dial.scad, end-stop.scad]
2025-07-02 New x-axis
    [config.yaml]
2025-07-15 Add Waste-Board
    [waste-board.scad]
2025-07-16 rename adapter
    [nut-housing-adapter.scad]
2025-07-16 New y-axis
    [config.yaml]
2025-07-17 First Coffee Time engraving
    [Coffee-Time.FCStd, Engrave.FCStd]
2025-07-18 Add Technocraft Bits
    [Coffee-Time.FCStd]
2025-07-18 real waste board
    [waste-board.scad]
2025-07-19 Start documenting the design
    [SRCNC.FCStd]
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2025-07-20 Define the frame in openscad
    [frame.scad, tramming-plate.scad, waste-board.scad]
2025-07-21 First steps with nopscad
    [srcnc.scad]
2025-07-21 setup project
    [main.scad, srcnc.scad]
2025-07-21 Improve y-axis
    [main.scad]
2025-07-21 Add generated files
    [bom.csv]
2025-07-21 Replace assembly by just normal module
    [main.scad]
2025-07-21 Add frame sides
    [bom.csv, frame_left_side.dxf, frame_right_side.dxf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]
2025-07-21 Add back side
    [bom.csv, main.scad]
2025-07-21 Forgot to add y-axis
    [bom.csv, main.scad]
2025-07-21 Add bottom frame
    [bom.csv, frame_bottom_side.dxf, main.scad]
2025-07-21 Add screws
    [bom.csv, main.scad]
2025-07-21 y-plate added
    [bom.csv, frame_left_side.dxf, frame_right_side.dxf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]
2025-07-21 Refactor z-plate
    [main.scad]
2025-07-21 Try exploding
    [main.scad]
2025-07-21 fix exploding
    [main.scad]
2025-07-21 Improve assembly
    [bom.csv, main.scad]
2025-07-21 add y motor
    [bom.csv, main.scad]
2025-07-22 Add mounting screws for y axis
    [bom.csv, main.scad]
2025-07-22 Add adapter plate
    [main.scad]
2025-07-22 Add generated stl
    [nut_housing_adapter.stl]
2025-07-22 First version of BF support
    [ball_screw_support.scad, ball_screw_supports.scad, bom.csv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]
2025-07-22 WIP: Initial version of fixed support
    [ball_screw_support.scad, ball_screw_supports.scad, test.scad]
2025-07-23 Improve floating ball screw support
    [ball_screw_support.scad, ball_screw_supports.scad]
2025-07-23 Add floating support
    [main.scad]
2025-07-23 build output
    [bom.csv, yplate.dxf]
2025-07-23 Add source file
    [ball_screw_supports.scad]
2025-07-23 fix BK support
    [ball_screw_support.scad, main.scad]
2025-07-23 Use screw and washer
    [main.scad]
2025-07-23 refactor to create xaxes
    [bom.csv, frame_right_side.dxf, main.scad]
2025-07-23 improve x-axis
    [frame_back_side.dxf, frame_xaxis.dxf, main.scad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]
2025-07-23 Fix assembly
    [bom.csv, main.scad]
2025-07-23 Fix SBR dimensions
    [bom.csv, frame_right_side.dxf, main.scad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]
2025-07-24 First z-plate version
    [bom.csv, main.scad, zplate.stl]
2025-07-24 Fix mounting screw positions
    [main.scad]
2025-07-24 Add z-plate mounting holes
    [main.scad]
2025-07-24 Assembly holes
    [main.scad, xplate.dxf, yplate.dxf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]
2025-07-24 First draft for linear table
    [linear_guide_table.scad, linear_guide_tables.scad]
2025-07-24 first draft of th linear guilde on the maschine
    [linear_guide_table.scad, linear_guide_tables.scad, main.scad]
2025-07-25 Improve linear guide table
    [ball_screw_support.scad, linear_guide_table.scad]
2025-07-25 Add floating block
    [linear_guide_table.scad, linear_guide_tables.scad]
2025-07-26 add zaxis assembly
    [bom.csv, linear_guide_table.scad, main.scad]
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2025-08-03 Tune acceleration, speed and microsteps
    [config.yaml]
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2026-07-14 Add DLC32 MAX V1.1 config, update FluidNC to v4.0.3, add bCNC launcher
    [config.yaml]
2026-07-14 Remove unused mks-dlc32-max config
    [config.yaml]
2026-07-14 Rename SRcnc to SRcnc-tinybee for consistency
    [config.yaml]
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2026-07-18 Fix endstop board socket pin order: 5V, GND, IO
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2026-07-18 Replace stepper image with stepper wiring diagram
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2026-07-18 Document level shifter requirement for DM542T (3.3V→5V), fix Makefile macrocfg path
2026-07-18 Add Flexi-HAL wiring docs and DIN rail mount STLs
    [DIN_Clip.stl, Flexi-HAL_Mount_Plate.stl]
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2026-07-21 Fix DM542T DIP switch settings: 5V signal, correct microstep table
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2026-07-23 Fix motor directions and homing: all axes working
    [config.yaml]
2026-07-23 Increase speeds: X/Y 3000mm/min, Z 1000mm/min, accel 100/50mm/s²
    [config.yaml]
2026-07-25 Add UGS configuration and setup
    - UGS config with FluidNC firmware, USB serial (/dev/cnc)
    - Tool library and firmware profiles
    - Launch script with Java 21, font AA, and Wayland workarounds
    - Self-documenting Makefile (setup/ugs/clean)
    - SENDERS.md documentation
    - Update grblhal Flexi-HAL README (IDC connectors included)
2026-07-25 Fix Y axis coordinate system and add tool setter support
    - Invert Y axis: Y0=back (home), Y+=front (standard convention)
    - Flip motor direction (remove :low from direction_pin)
    - Change homing to negative direction
    - Set mpos_mm to 0
    - Move limit switch from limit_pos_pin to limit_neg_pin
    - Configure toolsetter_pin as high:pu for NC switch
    - Update UGS macros for new coordinate system
    - Add Tool Setter Probe macro (X10 Y10)
    [config.yaml]
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2026-07-25 Move calibrate files from test/ to parts/
    [calibrate.FCStd, calibrate.scad]
2026-07-25 Add automated probe setup script and UGS workflow
    - probe/probe-setup.py: full 9-step automated CNC setup for pedalboard case
    - Safe homing (Z first), spoilboard probe, XY edge finding, case surface probe,
    tool change, Z probe with cross-check, G-code generation, UGS launch
    - Double-contact probing, feed hold on error, plausibility checks
    - Computed XY probe Z from spoilboard reference (fixes air-probing bug)
    - probe/mock-machine.py: GRBL/FluidNC simulator for testing without machine
    - Virtual serial port via Python pty, realistic probe contact geometry
    - --save-gcode flag records setup path for UGS visualizer
    - probe/README.md: full documentation
    - SENDERS.md: updated macros,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
2026-07-25 fluidnc: add touch plate pin, update wiring docs
    [config.yaml]
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2026-07-26 ugs: load fixture-plate.nc
2026-07-26 parts: reorganize into subdirectories
    - dc-plate/: electronics panel (scad + stl)
    - coffee-time/: Coffee-Time FreeCAD project + gcode
    - calibrate/: calibration square (scad + FreeCAD + gcode)
    - end-stop/: end-stop scad, BOSL2 reference updated to relative path
    - Remove .FCBak autosave files
    - BOSL2/ and flexi-hal/ remain in place
    [Coffee-Time.FCStd, calibrate.FCStd, calibrate.scad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]
2026-07-27 parts: move fixture plate from pedalboard-case repo
    Fixture plate is machine-specific, belongs in the cnc repo.
    - parts/fixture-plate/: OpenSCAD model, G-code generator, STL, NC, Makefile
    - 15mm MDF, 6 case holes (ø11mm counterbore + ø4mm through), 4 M5 carriage holes
    - Origin: plate center = machine X110 Y190
    [fixture-plate.scad, fixture-plate.stl]
2026-07-27 fluidnc: fix probe config — touchplate_pin not supported in FluidNC
    FluidNC only supports one probe input (probe: pin).
    Both 3D probe and touch plate share IO37, swap connector as needed.
    Door (IO38) reverted to unused.
    [config.yaml]
2026-07-27 fix: Z probe macro crashes into touch plate after setting WCS
    G0 Z10 in absolute G54 moves to 10mm above workpiece surface, but the
    19.25mm touch plate is still there → crash.
    Fix: retract 25mm in G91 before switching to G90 and setting WCS.
    G0 Z25 lifts clear of the plate, then G10 L20 P1 Z19.25 sets Z0 correctly.
2026-07-27 fix: Z probe macro - set WCS at contact then lift to Z25
2026-07-27 ugs: add macro test script to catch Z crashes into touch plate
    test-macros.py simulates each UGS macro against a virtual machine with
    a touch plate at a configurable Z position. Catches:
    - Tool moving into touch plate (as happened with old G0 Z10 bug)
    - Tool crashing below workpiece surface
    - Probe not triggering
    Run: make test
2026-07-27 fixture-plate: update for 12.7mm HPL board + #6-32 screws
    - Board: 12.7mm HPL/Trespa (was 15mm MDF)
    - Counterbore: ø10mm × 7.7mm (M4 washer, leaves 5mm below)
    - Shank: ø4.5mm helical (was ø4mm peck, too small for 4mm tool)
    - Screw: #6-32 × 12mm, 7mm engagement in case boss
    [fixture-plate.scad, fixture-plate.stl]
2026-07-27 fixture-plate: use outer SBR12UU carriage holes (±103×±74mm)
    [fixture-plate.scad, fixture-plate.stl]
2026-07-27 fixture-plate: carriage holes at ±73×±104mm (outer SBR12UU holes, corrected interpretation)
    [fixture-plate.scad, fixture-plate.stl]
2026-07-28 fixture-plate: carriage holes at ±73×±88mm (measured outer rectangle 146×176mm)
    [fixture-plate.scad, fixture-plate.stl]
2026-07-28 fixture-plate: update header with measured carriage dimensions
    [fixture-plate.scad]
2026-07-28 fixture-plate: use inner X (±48mm) × outer Y (±88mm) carriage holes
    [fixture-plate.scad, fixture-plate.stl]
2026-07-28 fixture-plate: case holes measured ±90×±55.5mm (180×111mm pattern)
    [fixture-plate.scad, fixture-plate.stl]
2026-07-28 fixture-plate: carriage holes ø6mm for position tolerance
    [fixture-plate.scad, fixture-plate.stl]
2026-07-28 fixture-plate: safe Z=15mm, initial approach from center at Z0
    - rapid_to() retracts to Z=15mm (clears clamps up to ~10mm above workpiece)
    - Program starts by moving to machine center at Z0 before any lateral moves
    - Prevents crashes into edge clamps during tool approach
2026-07-28 agent: add G-code safety rules to srcnc prompt
    Lessons learned from crash into clamps:
    - Safe Z = 15mm minimum
    - Initial approach from machine center at Z0
    - Z first, then XY for all rapids
    - Never move to WCS position while touch plate is present
    - Double-contact probing always
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2026-07-29 flexihal: =7 (invert limit pins for NO switches)
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2026-07-29 flexihal: homing verified working with 3-axis firmware
    - $23=3 confirmed correct (X+Y inverted)
    - All axes home successfully
    - 3-axis firmware (no ganged axis) resolves alarm 15
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2026-07-30 flexihal: $6=1 (invert probe pin for NO probes)
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2026-07-30 Set machine origin to 0 after homing (=9)
    Enable grblHAL 'Set machine origin to 0' (bit 3 of $22). After homing,
    MPos reports 0,0,0 with X/Y traveling positive into the workspace and
    Z traveling negative downward. This is the natural convention:
    X: 0 (home/left) → +220 (right)
    Y: 0 (home/back) → +380 (front)
    Z: 0 (home/top) → -95 (bottom)
    Revert $27 to 2mm (no longer need the 1mm workaround since Z-1 is now
    valid in this coordinate system).
    Remove $73/$74/$75 (were WiFi settings on this firmware, not homing
    offsets as previously assumed).
    Update macros and gSender park config to use positive X/Y coordinates.
    Park at X20 for router switch access.
2026-07-31 probe-setup: launch gSender instead of UGS, check if already running
    - Replace UGS launch with gSender at end of workflow
    - Add check at startup that gSender is not already running
    (would hold the serial port)
2026-07-31 probe-setup: fix for new coordinate system and real hardware
    - Enable single axis homing ($22=11, adds bit 1)
    - Add $X unlock before homing (handles alarm state after reset)
    - Increase homing timeout to 120s (slow seek + locate)
    - Replace G38.3 safe_descend with plain G0 moves (avoids probe
    state issues, matches working Z probe macro pattern)
    - Update spoilboard probe position to X=10 Y=190 (on fixture plate)
    - Increase PROBE_TRAVEL_Z to 90mm (reaches spoilboard in mock)
    - Add Makefile test target (runs against mock-machine simulator)
    - Launch gSender instead of UGS, check if already running
2026-07-31 probe-setup: remove unused safe_descend method
    All probe scripts use plain G0 for positioning and G38.2 for probing.
    G38.3 safe descent caused probe state issues (error 30) and is not
    used by any standard probe workflow.
2026-07-31 probe-setup: measure angle on long edge (X- at two Y positions)
    Better angle resolution by probing the long edge (182mm Y direction)
    instead of the short edge (114mm X direction). Same 120mm baseline
    but along the more stable dimension.
    Probe sequence is now:
    1. X- edge at center Y (for X center)
    2. X+ edge at center Y (for X center)
    3. Y- edge at center X (for Y center)
    4. X- edge at Y=130 (angle point front)
    5. X- edge at Y=250 (angle point back)
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2026-07-31 Fix formatting in README.md for probe section
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2026-07-31 probe-setup: probe all 4 edges for center (no dimension assumptions)
    Probe 5 points total:
    - X- edge at two Y positions (left edge + angle)
    - X+ edge (right edge)
    - Y- edge (front edge)
    - Y+ edge (back edge)
    Center is computed purely from measured opposing edges (midpoints).
    No case dimension assumptions needed. Angled sidewalls don't affect
    results since all probes are at the same Z height.
    Also fix mock-machine stale symlink handling and add run_test.py
    helper for reliable test execution.
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2026-07-31 Revise probe diagram with corrected coordinates
    Updated diagram in README to reflect accurate coordinates and positions.
2026-07-31 mock-machine: fix X-axis probing to account for rotation angle
    X probes now correctly simulate the effect of case rotation on the
    left/right edge positions at different Y coordinates. Verified:
    --angle 0.5 → measured -0.4999°
    --angle -0.5 → measured +0.4999°
2026-07-31 probe-setup: fix probe response timing for real hardware
    grblHAL sends 'ok' immediately when G38.2 is accepted into the
    motion planner buffer. The [PRB:] response comes later when the
    probe physically triggers (up to 54s for 90mm at 100mm/min).
    Remove the 0.5s post-ok deadline and keep waiting with full timeout.
    Increase TIMEOUT to 90s to cover worst-case probe travel.
2026-07-31 probe-setup: handle startup spam and make $X unlock non-fatal
    - Extend startup read to 5s with 1s extension while data flows
    (Flexi-HAL dumps plugin list on reset)
    - Make $X unlock non-fatal (ignore timeout if already idle)
2026-07-31 probe-setup: add manual probe trigger confirmation before probing
    Like gSender's 'touch the plate to confirm' step. Before each probing
    phase, the script:
    1. Verifies probe is NOT triggered (idle state)
    2. Asks user to manually trigger it (touch tip / touch plate)
    3. Verifies probe IS triggered
    4. Asks user to release
    5. Verifies probe is released
    Confirms full probe circuit works before any automatic probing move.
    Skipped automatically in non-interactive mode (piped stdin/tests).
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2026-07-31 probe-setup: fix Z probe travel to stay within soft limits
    Reduce PROBE_TRAVEL_Z to 80mm (from Z=-10, stays within Z=-90,
    well inside the -95 soft limit). Mock machine updated to use
    realistic fixture plate height (Z=-60) instead of machine bottom.
2026-07-31 mock-machine: set spoilboard to measured Z=-65 (matches real fixture plate)
2026-07-31 probe-setup: retract away from wall before Z retract
    After slow probe contacts the case wall, retract 2mm laterally
    before retracting Z. Prevents dragging probe tip along the wall.
    Added probe-path.nc for visualizing the motion path in gSender.
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2026-07-31 probe-setup: increase approach clearance to 20mm (probe travel 35mm)
    More comfortable margin between approach position and case edge.
    Reduces crash risk if case is slightly off-center.
2026-07-31 probe: update probe-path.nc with 20mm clearance and Z offset
2026-07-31 probe-setup: update case height to 33mm (measured) and relax tolerance to 5mm
2026-07-31 probe-setup: remove Z cross-check (invalid with different tool lengths)
    The 3D probe and cutting tool have different lengths, so comparing
    their Z contact points is meaningless without tool length offsets.
    The touch plate G10 L20 sets Z0 correctly regardless.
2026-07-31 probe-setup: reset machine to Idle after error (feed hold + resume + soft reset)
2026-07-31 probe-setup: handle Hold/Alarm state on startup (soft reset or unlock)
    If the machine is in Hold state from a previous failed run, send
    soft reset to return to Idle. If in Alarm state, let the existing
    $X unlock handle it. No longer aborts on Alarm — just recovers.
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2026-07-31 probe-setup: fix G54 XY offset (use G10 L2 instead of L20)
    G10 L20 sets offset relative to current position, but the probe
    is at the last edge position, not the center. G10 L2 sets the
    offset directly: work = machine - offset. Setting offset = center
    means work = 0 when at the center.
2026-07-31 probe-setup: fix G54 XY - move to center then G10 L20 X0 Y0
    G10 L2 not supported on this grblHAL build. Instead, move to the
    computed center position first, then use G10 L20 P1 X0 Y0 to set
    current position as the work origin.
2026-07-31 probe-setup: add per-feature Z probing for surface compensation
    After finding center/angle, probe Z at each feature center (12 points:
    2 LEDs, 6 buttons, 2 encoders, 2 displays). Save offsets to
    z-offsets.json, passed to G-code generator for per-feature Z correction.
    Also: revert center Z probe offset (was workaround for practice case),
    skip gSender check when using non-default port (for testing).
2026-07-31 probe-setup: fix slow Z probe travel (5mm, not 16mm)
    After fast probe contacts and retracts 2mm, the slow probe only needs
    5mm travel to re-contact. The previous 16mm (80/5) could exceed soft
    limits when probing deep surfaces (e.g. spoilboard at Z=-87).
2026-07-31 probe-setup: make G54 readback a warning, not fatal error
    The G10 L20 command succeeded (got ok). The $# readback is just
    verification — if it fails due to timing, the offset is still set.
    Don't abort the entire workflow for a cosmetic check.
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2026-08-01 probe-setup: add --skip-feature-probing and --z-probe-offset for rework
    For rework cuts on already-machined cases:
    - --skip-feature-probing: reuse existing z-offsets.json, skip probing
    at feature centers (which now have holes)
    - --z-probe-offset X Y: probe Z surface at a custom work coordinate
    instead of case center (which may have a hole)
    - When skipping feature probing, generates displays-only G-code
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
